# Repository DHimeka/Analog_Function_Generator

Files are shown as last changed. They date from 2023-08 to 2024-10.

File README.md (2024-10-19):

# 🎛️ Analog Function Generator
This project is a fully functional function generator designed during the third semester for the module EN2091 - Laboratory Practice and Projects. It incorporates essential features commonly found in laboratory-grade devices, combining versatility with performance.

  

## Usage/Examples

Usage examples will be included here, showcasing how to operate the function generator for various applications.

## Features

- Generation of sine, square, triangular, sawtooth, and PWM waveforms
- Frequency control from 20Hz to 20kHz
- Amplitude control from 0V to 20V with DC offset adjustment
- Compatibility with a 50 Ω load

## Introduction

This is the project done during the third semester for the module EN2091 - Laboratory Practice and Projects. During the course of this project, Our team had the privilege of designing and developing a fully functional function generator that seamlessly incorporates essential features commonly found in laboratory-grade devices. With a clear focus on versatility and performance, we harnessed the potential of basic electronic components, including opamps, transistors, resistors, capacitors, and potentiometers, to achieve waveform generation and control with optimum precision. Through an extensive research and a meticulous design, we successfully utilized analog electronic calculations to generate sine, square, triangular, sawtooth, and PWM waveforms. We ensured accurate frequency control across the impressive range of 20Hz to 20kHz, empowering users to tailor the function generator to their specific experimental requirements. A key aspect of the project was the robust control over amplitude and DC offset. Employing feedback mechanisms and precise opamp configurations, we allowed users to manipulate the output voltage from a 0V to 20V and introduce desired DC offsets for waveform customization. Throughout the endeavor, we encountered and various challenges, from refining the circuits iteratively to optimize performance, building up enclosures, making pcbs to presenting a marketable prooduct. Yet the outcome was worthful and impressive. The result is a fully functional and adaptable function generator, seamlessly blending the artistry of creative circuit design with the precision of engineering finesse.

## Electronic Design

### Design Guidelines
The project adhered to specific design requirements, including waveform generation, frequency, amplitude, PWM control, and 50 Ω load compatibility. These guidelines influenced the electronic design decisions.

### Waveform Generation
- **Square Wave and PWM Wave Generation:** A Schmitt trigger circuit generates square waves, which can be further modified to achieve PWM waves with adjustable duty cycles.
- **Triangular Wave and Sawtooth Generation:** Triangular and sawtooth waveforms are generated through a capacitor-based charging and discharging process, with frequency control.
- **Sine Wave Generation:** A Wien bridge oscillator generates sine waves, which can be adjusted for frequency.

### Output Circuit
The output circuit handles waveform selection, probe selection (1x and 10x), amplitude control, and push-pull amplification to drive a 50 Ω load.

### Calculations and Component Selection
Careful component selection and calculations were crucial for ensuring proper functionality. The NE5532n operational amplifier was chosen for its low noise and appropriate gain-bandwidth product. Transistors TIP31C and TIP32C were selected to handle the required power and current.

### Simulations
NI Multisim was used for circuit simulations to validate the design before proceeding to PCB fabrication. Simulations confirmed that the circuit met the desired specifications.

### Testing
After simulation, the circuit was implemented on a breadboard and tested. Issues related to waveform interference and instability were addressed through careful circuit adjustment and troubleshooting.

### PCB Designing and Soldering
The PCB was designed using Altium and printed through JLCPCB in a two-layer configuration. Soldering was done with locally sourced components to create a physical circuit.

## Results

The project successfully achieved the following results:
- Generation of square, triangular, sawtooth, and sine waves within the specified frequency and amplitude ranges.
- PWM wave generation with adjustable duty cycles.
- Compatibility with a 50 Ω load.

## Enclosure Design

The enclosure for the function generator was designed using Solidworks 2020, ensuring a suitable physical housing for the device.

## Discussions

The project team encountered challenges with waveform distortions at high frequencies. Strategies to mitigate these distortions, including the use of high-quality components and minimizing wire resistance, were discussed.

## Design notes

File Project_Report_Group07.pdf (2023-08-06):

## University of Moratuwa

## Faculty of Engineering

## Department of Electronic & Telecommunication Engineering

EN2091 - Laboratory Practice and Projects Group 07
Project Report - Analog Function Generator

Group Members

Index No. | Name
200051J 200222K 200396U 200564J | Arukgoda A.M.O Himeka S.H.D Miranda C.M.C.C Samaraweera D.T

Abstract

In this report there is a detailed description of how to build an analog function generator which can generate Sine, Saw-tooth, Square (with adjustable duty cycle) waves with adjustable amplitude, frequency and a DC shift. The amplitudes can be varied from 0 V to 10 V and frequencies can be varied from 20 Hz to 20 kHz. This project was done by mainly using op-amps, resistors and capacitors.

## Contents

1 Introduction | 1
2 Electronic Design | 1
3 Calculations and Component Selection | 4
4 Simulations | 5
5 Testing | 6
6 PCB Designing and Soldering | 6
7 Results | 7
8 Enclosure Design | 8
9 Discussions | 8
10 Acknowledgement | 9
11 Bibliography | 9
12 Appendices | 10

## 1 Introduction

For this project, we were asked to make a fully functional function generator which includes all the key functionalities of a laboratory function generator.Generation of sine, square, triangular, sawtooth and PWM wave forms are the main functionalities of the function generator.Other than that, this function generator is capable of changing the frequency of the wave forms from 20Hz to 20kHz and the amplitude from 0 to 20V. Adding a DC offset to the wave forms and add a changing the duty cycle of square wave are the other functionalities of the function generator.In the past, these functionalities were produced b7y some popular Integrated Circuits(ICs).Now these old analog ICs are replaced with new Direct Digital Synthesis chips.In this project, only opamps, transistors, resistors capacitors and potentiometers were used to generate all the wave forms.In this report, the different techniques which were used to generate wave forms and change the characteristics of the wave forms will be described.

## 2 Electronic Design

### 2.1 Design Guidelines

For the analog function generator project we were given the following specifications to be fulfilled.

1. The function generator should be able to generate sine, triangular, saw-tooth, square and pulse width modulation (PWM) waves.
2. The frequencies of the waves should be able to vary from 20 Hz to 20 kHz.
3. The amplitudes of the waves should be able to vary up to 20 V peak-topeak.
4. In PWM wave, the pulse width should be able to vary from 1% up to 99%.
5. The function generator should be able to supply the waves to a 50 Ω load.

### 2.2 Waveform Generation

As the given specifications, the function generator should be able to generate five functions namely, sine wave, square wave, triangular wave and PWM wave. We used separate methods to generate these wave forms to reduce the effect of one waveform on other wave forms.

### 2.2.1 Square Wave and PWM wave

Generation

Both the square wave and PWM wave forms can be generated using the same circuit because the square wave is the PWM wave with a duty cycle of 50%.
To generate the square wave, we used a schmitt trigger circuit.Schmitt trigger circuit produces a square wave when producing clock or timing signals which swaps between high and low.The frequency of the square wave depends on the value of Resistance and the capacitance.

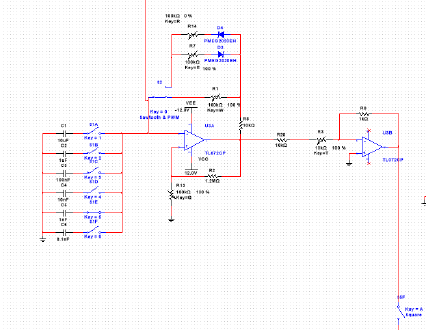
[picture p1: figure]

Figure 1: Square wave generator circuit.

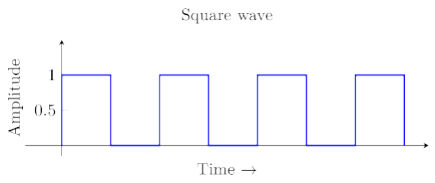
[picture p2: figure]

Figure 2: Square wave

The square wave generated from Schmitt trigger circuit will be headed to a Inverting attenuator in order reduce the output voltage to a more useful voltage.It is because the the highest output voltage from the relaxation oscillator will be not useful at this point of the circuit.
The duty cycle of the square wave generated by the Schmitt trigger circuit can be controlled by the Schottky Diodes circuit.

Figure 3: Square wave attenuator circuit.

By adjusting the potentiometers we can control the duty cycle percentage. The frequency of the square wave depends on the value of Resistance and the capacitance.

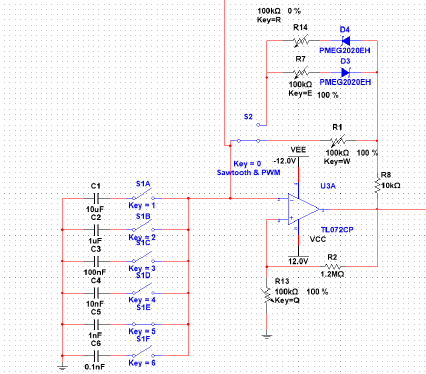
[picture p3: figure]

Figure 4: PWM circuit.

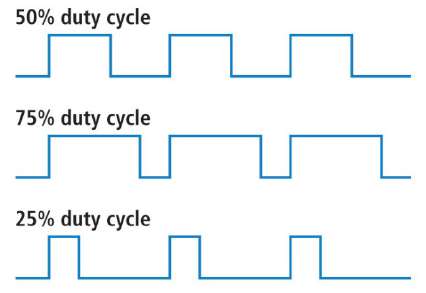
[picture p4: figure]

Figure 5: PWM Wave

### 2.2.2 Triangular Wave and Saw tooth

Generation

The triangular waveform is generated using the simple charging and discharging property of a capacitor.The frequency can be varied by changing the value of the capacitor and the variable resistors of the Schmitt

Trigger circuit.This is the same that was used to generate square wave. The out from

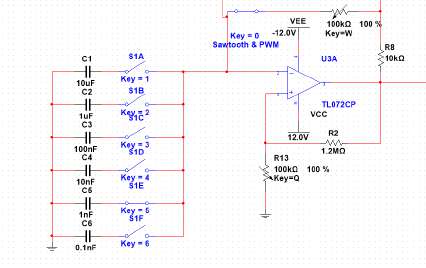
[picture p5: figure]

Figure 6: Schmitt trigger circuit of triangular wave generator

the capacitor panel will then be connected to a non-inverting amplifier that ”picks off” the triangle wave from the capacitor.Non-inverting amplifier configurations are useful because they have extremely high input impedance. The actual charge on the capacitor is very small, and any significant current draw from that point can ruin the operation of the relaxation oscillator. The

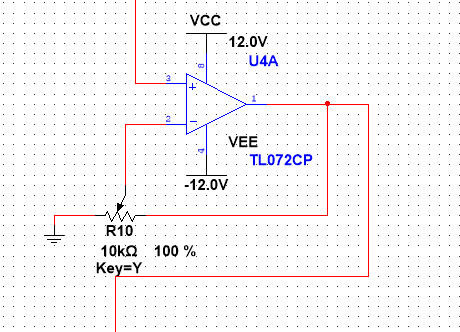
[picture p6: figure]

Figure 7: Non-inverting amplifier of triangular wave generating circuit

Figure 8: Triangular wave

saw-tooth waveform is generated using the simple charging and discharging property of a capacitor and the Schottky diodes circuit along with the Schmitt Trigger circuit .The ramp of the saw-tooth can be controlled by potentiometers.Frequency control is same as the triangular waveform.

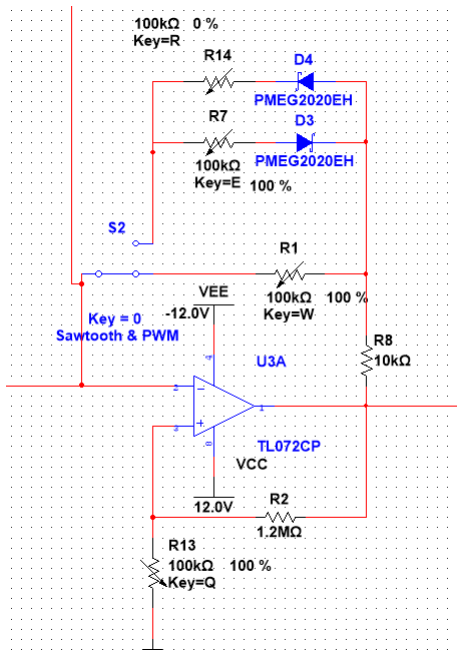
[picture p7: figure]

Figure 9: Saw tooth waveform generating circuit

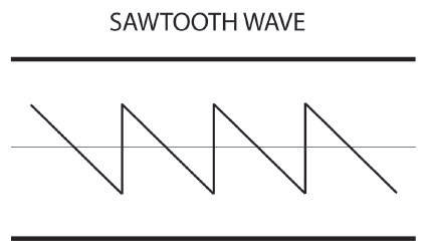
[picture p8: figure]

Figure 10: Sawtooth wave

### 2.2.3 Sine Wave Generation

To generate the sine wave, in our project, wien bridge oscillator is used.This generates a sine wave at the resonance frequency (fr), given by the equation,

F =

1
2πrc
The frequency of the sine wave can be changed by varying the values of the two resistors or

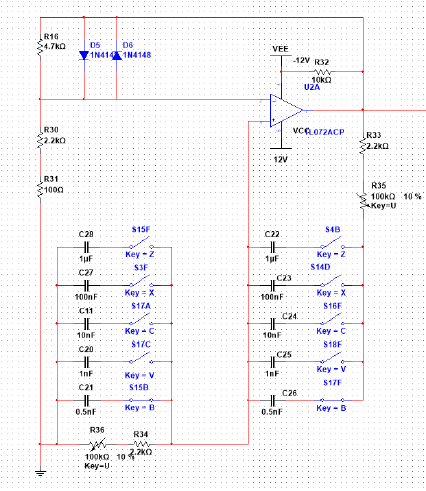
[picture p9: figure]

Figure 11: Wien bridge oscillator for sine wave generation

Figure 12: Sine wave.

the two capacitors simultaneously. An Inverting Amplifier that is used to calibrate the sine wave.A low-pass filter before will be useful to eliminate some of the overtones and make a prettier sine wave.A high pass filter after the amplifier will eliminate any offset remaining after the drift correction.

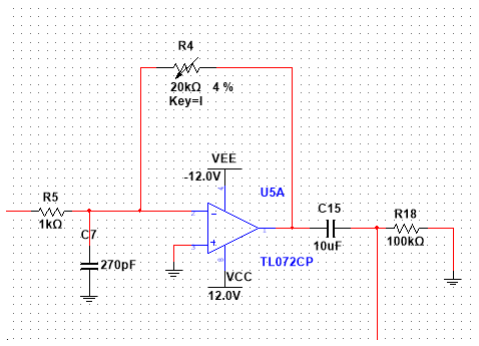
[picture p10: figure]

Figure 13: Inverting amplifier of sine wave generating circuit

### 2.3 Output Circuit

The output circuit of the function generator gives the ability to change the amplitudes, give dc shifts and to provide the output through a small load.The amplitude variation is done using an inverting amplifier. A push-pull amplifier is used to drive the load.

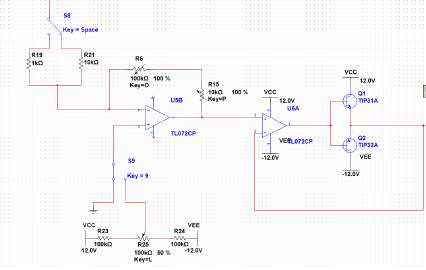
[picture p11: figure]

Figure 14: Output circuit

### 2.3.1 Waveform selection

Between the sine,square,triangular circuits and the output circuit, a switch is used to select which waveform generating circuit should be connected to the output circuit.

Figure 15: Waveform selection

### 2.3.2 Probe selection

This switch is used to change the probe between 1x and 10x. It can be used to change the amplitude range.

### 2.3.3 Amplitude control

An inverting amplifier is being used to vary the amplitude of he waveform.The main amplitude change of the wave forms is done using this amplifier.

### 2.3.4 Push pull amplifier

At the output stage of the function generator a push-pull amplifier is used to am-

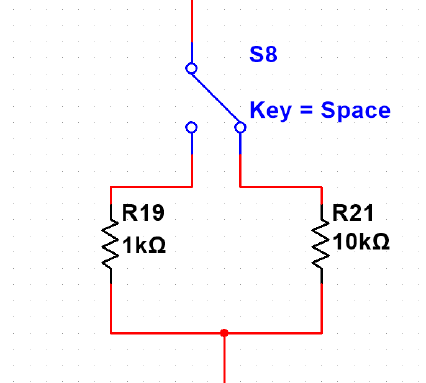
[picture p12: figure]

Figure 16: Probe selection

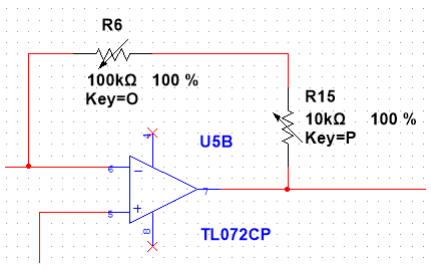
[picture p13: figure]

Figure 17: Amplitude Control

plify the current. This helps it to drive a small load without any distortion in the wave. In the design a class-AB push-pull amplifier is used.The two pnp and npn transistors are complementary to each other. The npn transistor drives the output during the positive half cycle of the input while the pnp transistor drives the output during the negative half cycle. These transistors should also be capable of handling the desired amount of power and current. The two diodes keep both the transistors biased thus eliminating the crossover distortion.

## 3 Calculations and Component Selection

For the correct functionality of the function generator, selecting components is very important. We have done this using necessary calculations and by referring to the data sheets of the components.

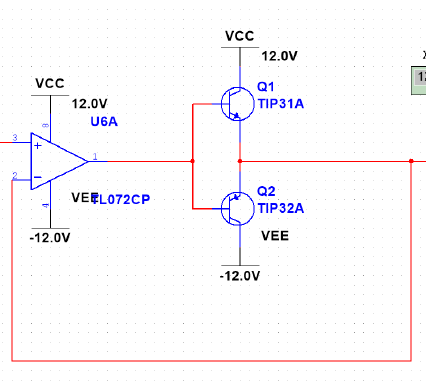
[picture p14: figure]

Figure 18: Push pull amplifier

### 3.1 Opamp selection

In this circuit, all the waveform generations and amplifications are done using opamps.We have selected NE5532n opamp to meet the given specifications. This low noise op-amp

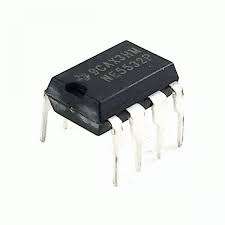
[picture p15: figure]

Figure 19: NE5532 Opamp

has a high slew rate of 9 V/µs. This is an important factor specially in square wave generation. This op-amp also has a gainbandwidth product(GBP) of 10 MHz. The required bandwidth for the function generator is 20 kHz. Therefore the maximum gain that can be achieved without any distortion can be calculated as below.

M aximumGain =

10x10⁶
2x10³ = 500

This is more than sufficient to generate the 20V peak to peak output waveforms.

### 3.2 Transistor selection

To drive a small current through the function generator, push pull amplifier is used. Maximum power calculations of 50Ω load is given below.

M aximumP ower =

10²
50 = 2W

M aximumGain =

10
50 = 200mA

The transistors we used are TIP31C and TIP32C and these transistors are capable of providing 40W power and a maximum collector current of 3A and these can handle required power and current easily.

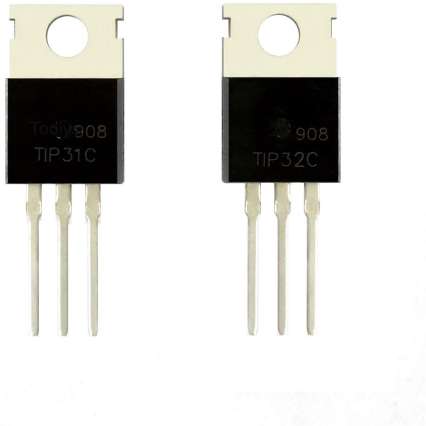
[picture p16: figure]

Figure 20: TIP31C AND TIP32C Transistors

## 4 Simulations

We used NI Multisim to simulate the circuit before designing the PCB.All the required waveforms were generated and their characteristics could be changed correctly using the simulation.NI Multisim simulation is shown below.

Figure 21: NI Multisim simulation circuit

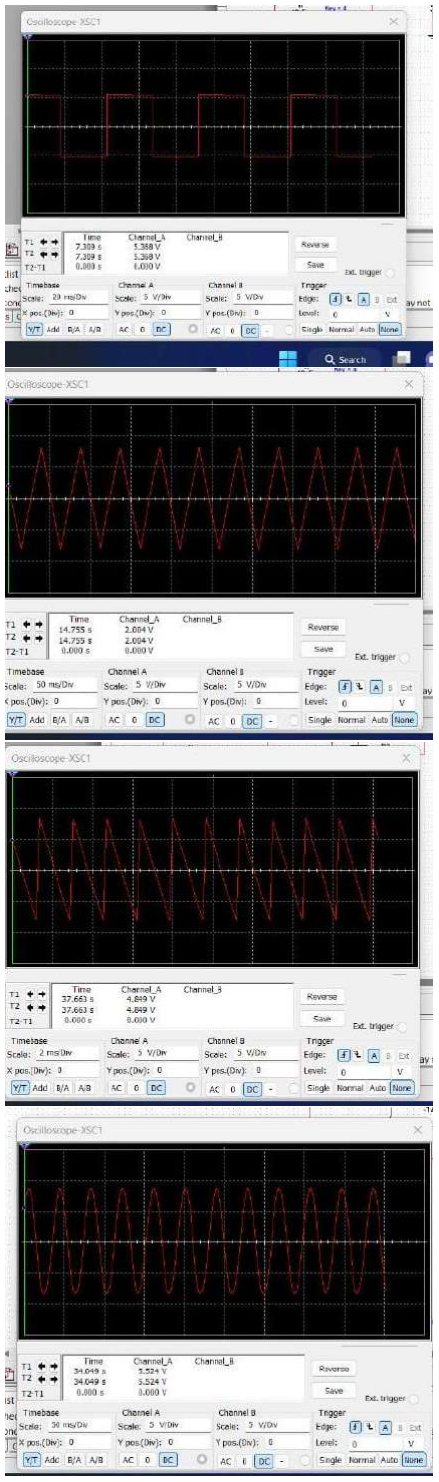
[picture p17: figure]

Figure 22: NI Multisim simulation waveforms

## 5 Testing

After the circuit simulations, we implemented the circuit in the breadboard and tested it. We encountered some issues but after a few attempts, we could get clear waveforms with adjustable frequencies and amplitudes in the advised range. The Wien bridge oscillator generated sin wave was affecting the other square and triangular wave forms. We could minimize this issue up to a certain level using decoupling capacitors for each IC.We concluded that the major instabilities of the wave forms were due to loose connections and a breadboard and wire resistance.

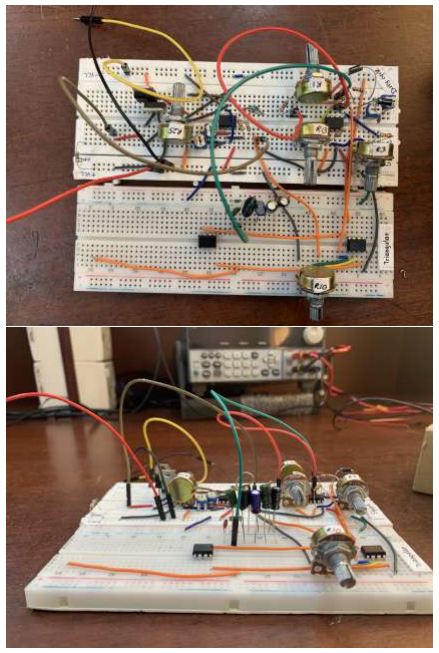
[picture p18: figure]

Figure 23: Breadboard Testing.

## 6 PCB Designing and Soldering

Next, we proceeded with the PCB design. We designed a two-layer PCB using Altium designing 22.4.1. The two planes were connected to the ground. We added a separate copper pour for the copper plane for better signal quality. Since our circuit does draw a current of more than A, we set our trace normal line trace width to 0.2mm while the power line width was kept at 3mm. We

## 7 Results

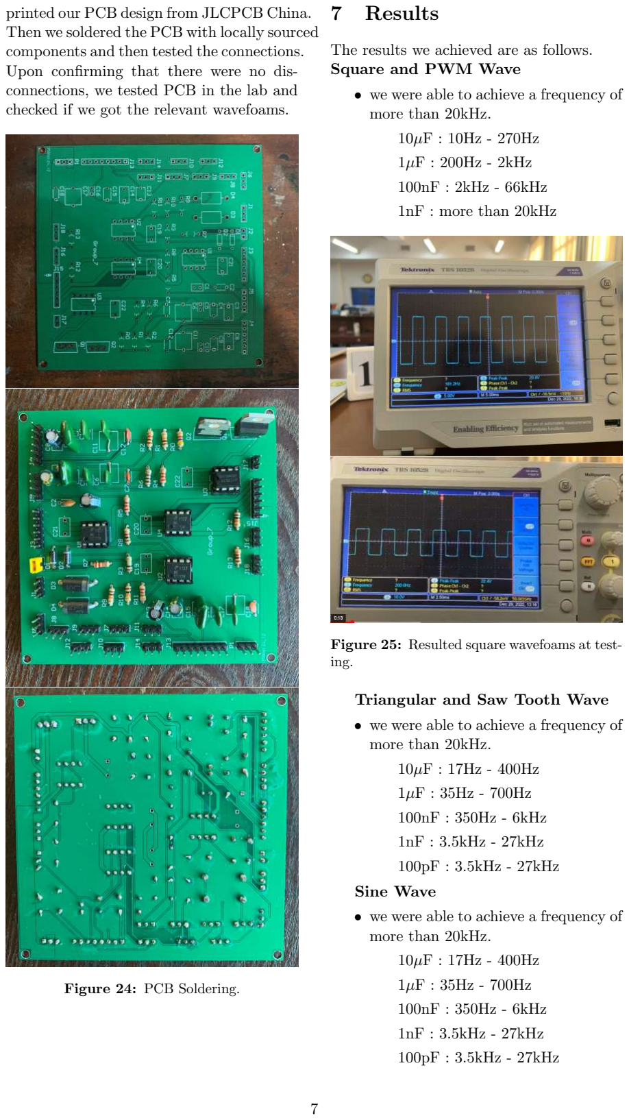
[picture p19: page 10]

printed our PCB design from JLCPCB China. Then we soldered the PCB with locally sourced components and then tested the connections. Upon confirming that there were no disconnections, we tested PCB in the lab and checked if we got the relevant wavefoams.

Figure 24: PCB Soldering.

The results we achieved are as follows. Square and PWM Wave
- we were able to achieve a frequency of more than 20kHz.

10µF : 10Hz - 270Hz

1µF : 200Hz - 2kHz

100nF : 2kHz - 66kHz

1nF : more than 20kHz

Figure 25: Resulted square wavefoams at testing.

Triangular and Saw Tooth Wave
- we were able to achieve a frequency of more than 20kHz.

10µF : 17Hz - 400Hz

1µF : 35Hz - 700Hz

100nF : 350Hz - 6kHz

1nF : 3.5kHz - 27kHz

100pF : 3.5kHz - 27kHz

Sine Wave
- we were able to achieve a frequency of more than 20kHz.

10µF : 17Hz - 400Hz

1µF : 35Hz - 700Hz

100nF : 350Hz - 6kHz

1nF : 3.5kHz - 27kHz

100pF : 3.5kHz - 27kHz

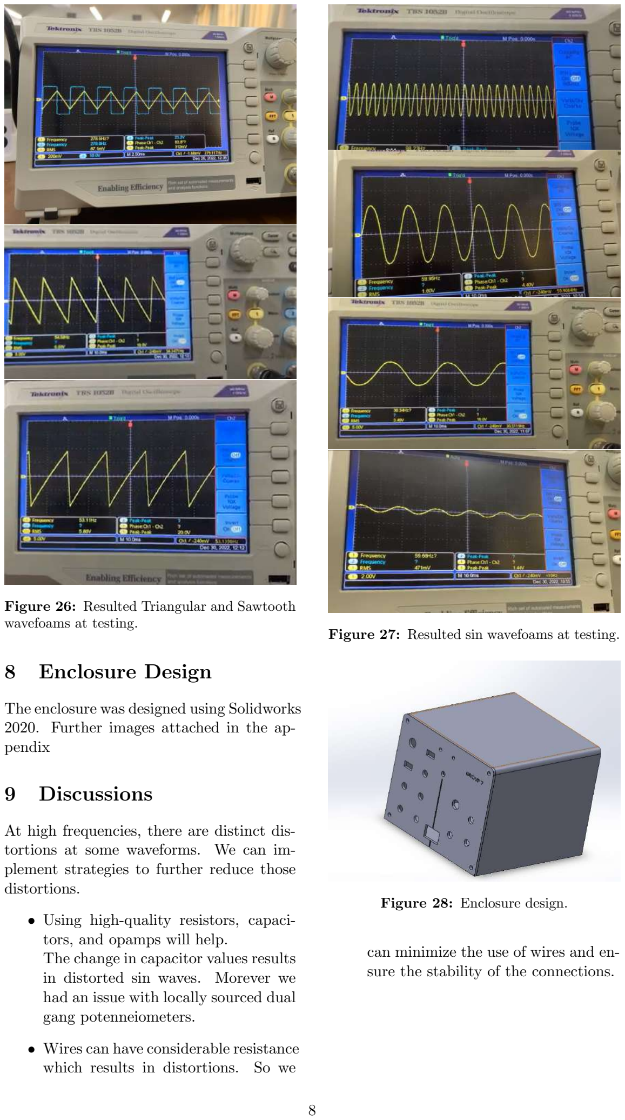
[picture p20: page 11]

Figure 26: Resulted Triangular and Sawtooth wavefoams at testing.

## 8 Enclosure Design

The enclosure was designed using Solidworks 2020. Further images attached in the appendix

## 9 Discussions

At high frequencies, there are distinct distortions at some waveforms. We can implement strategies to further reduce those distortions.

- Using high-quality resistors, capacitors, and opamps will help.
The change in capacitor values results in distorted sin waves. Morever we had an issue with locally sourced dual gang potenneiometers.
- Wires can have considerable resistance which results in distortions. So we

Figure 27: Resulted sin wavefoams at testing.

Figure 28: Enclosure design.

can minimize the use of wires and ensure the stability of the connections.

## 10 Acknowledgement

Throughout this project, we were guided and aided by so many personalities. We would like to extend our sincere gratitude to our project mentors, Mr.Pahan, Mr.Chamath and Ms. Sandani, whose unwavering commitment and keen enthusiasm in our undertaking contributed to the success of our project. Additionally, we would like to thank all those who contributed in even the slightest way for us to achieve this goal.

## 11 Bibliography

1. Generating Sine Waves from Triangle Waves (https://www.analog.com/en/analog-dialogue/studentzone/studentzone-september-2021.html)
2. Sine Wave Generator using IC 741 OP AMP Operational Amplifier (https://www.electroniclinic.com/sine-wave-generator-using-ic-741-op-amp-operational-amplifier/)
3. Wien Bridge Sine Wave Oscillator / Generator (https://www.electronics-notes.com/articles/analogue_circuits/operational-amplifier-op-amp/wien-bridge-sine-wave-oscillator-generator.php)
4. Philip Karantzalis, Aaron Schultz, and Catherine Chang,Lower Power Op Amp: Utility Sine Wave (https://www.analog.com/en/technical-articles/lower-power-op-amp-utility-sine-wave.html)
5. Waveform Generator using Op Amp 741 (https://vikramlearning.com/jntuh/notes/ic-applications-and-hdl-simulation-lab/waveform-generator-using-op-amp-741/298)
6. Wien Bridge Oscillators (https://learnabout-electronics.org/Oscillators/osc34.php)
7. Limited Wien-Bridge Oscillator Amplitude (https://electronics.stackexchange.com/questions/167196/limited-wien-bridge-oscillator-amplitude)
8. Analog Function Generator (https://www.instructables.com/Function-Generator/)
9. Increase Amplifier Output Drive Using a Push-Pull Amplifier Stage (https://www.analog.com/en/technical-articles/increase-amplifier-output-drive-using-a-push-pull-amplifier-stage.html)

## 12 Appendices

### 12.1 Schematic Design

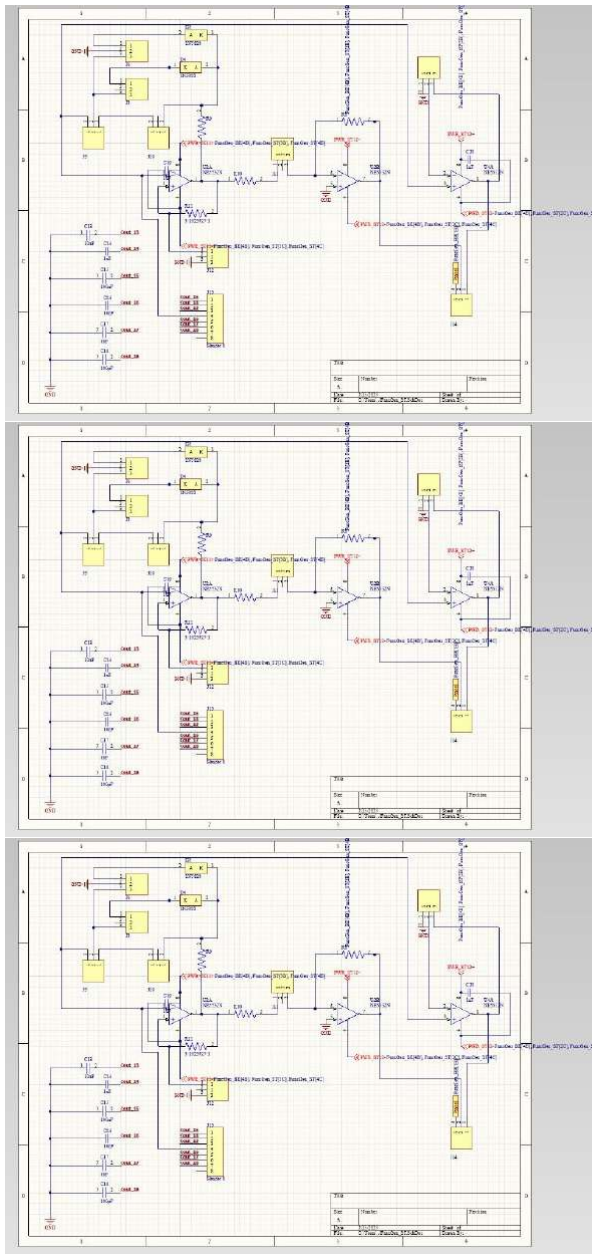
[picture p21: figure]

Figure 29: Schematic

### 12.2 PCB Design

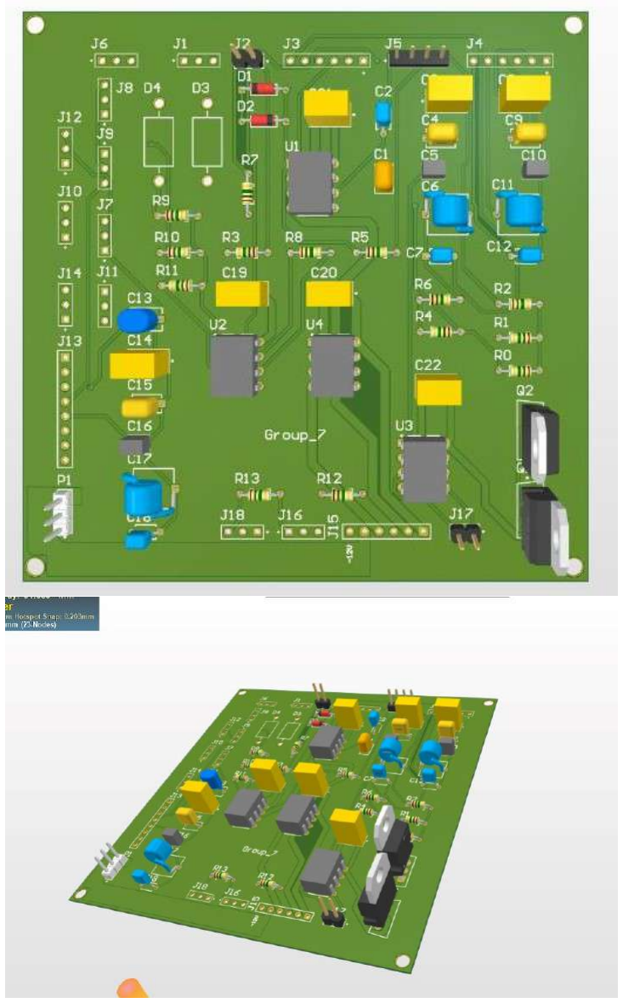
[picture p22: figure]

Figure 30: PCB

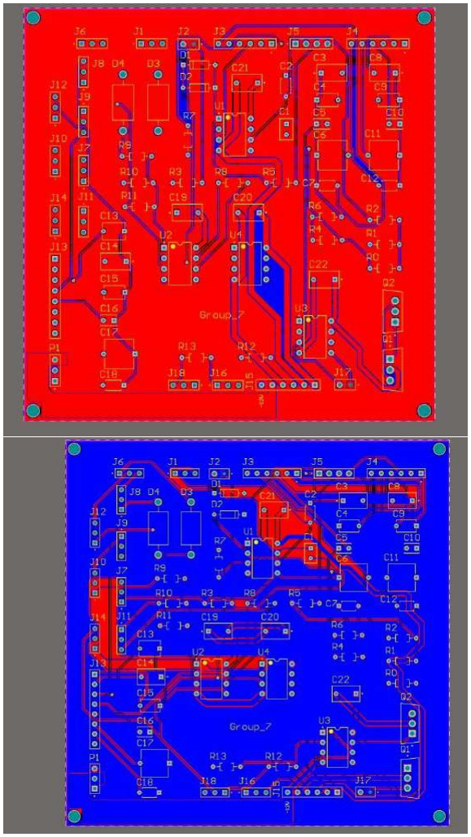
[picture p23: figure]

Figure 31: PCB

### 12.3 Enclosure Design

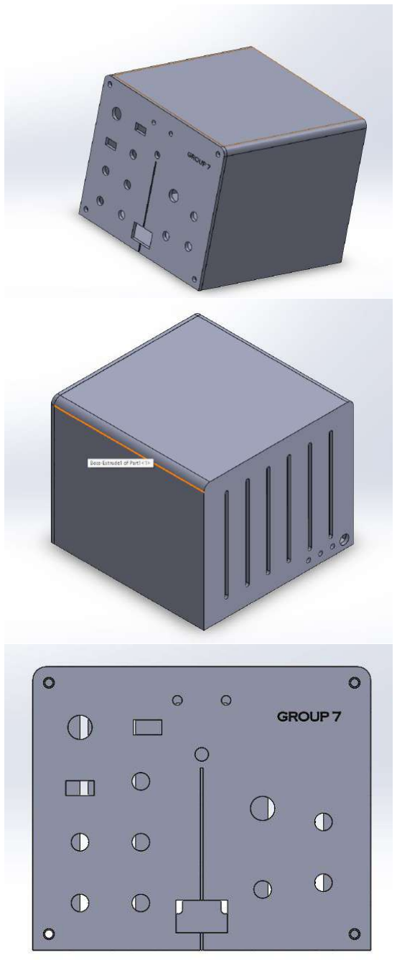
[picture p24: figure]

Figure 32: Enclosure

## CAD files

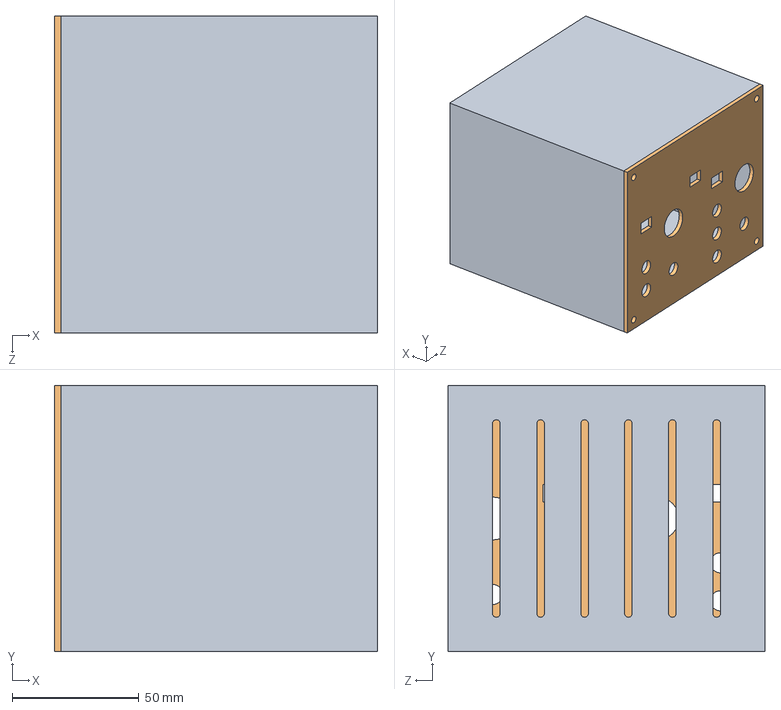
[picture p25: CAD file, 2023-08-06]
Enclosure/Assem1.SLDASM
127.5 x 105.0 x 125.0 mm

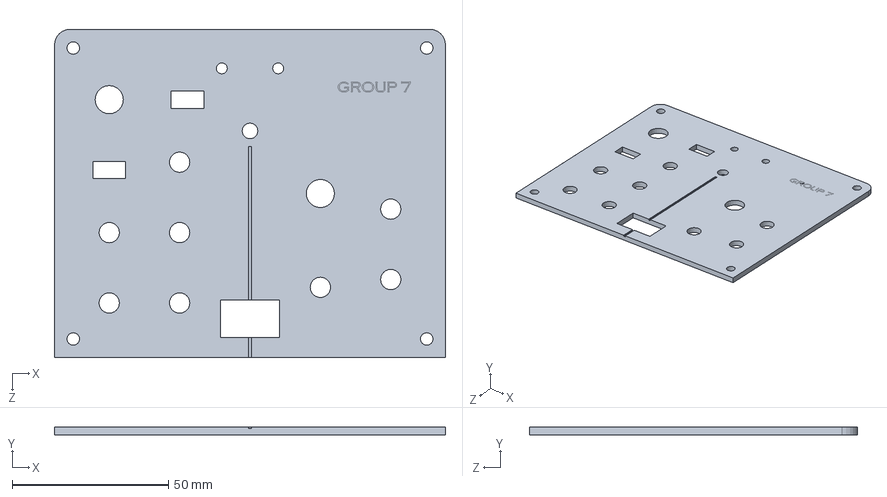
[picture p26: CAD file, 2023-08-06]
Enclosure/Part2.SLDPRT
125.0 x 2.50 x 105.0 mm

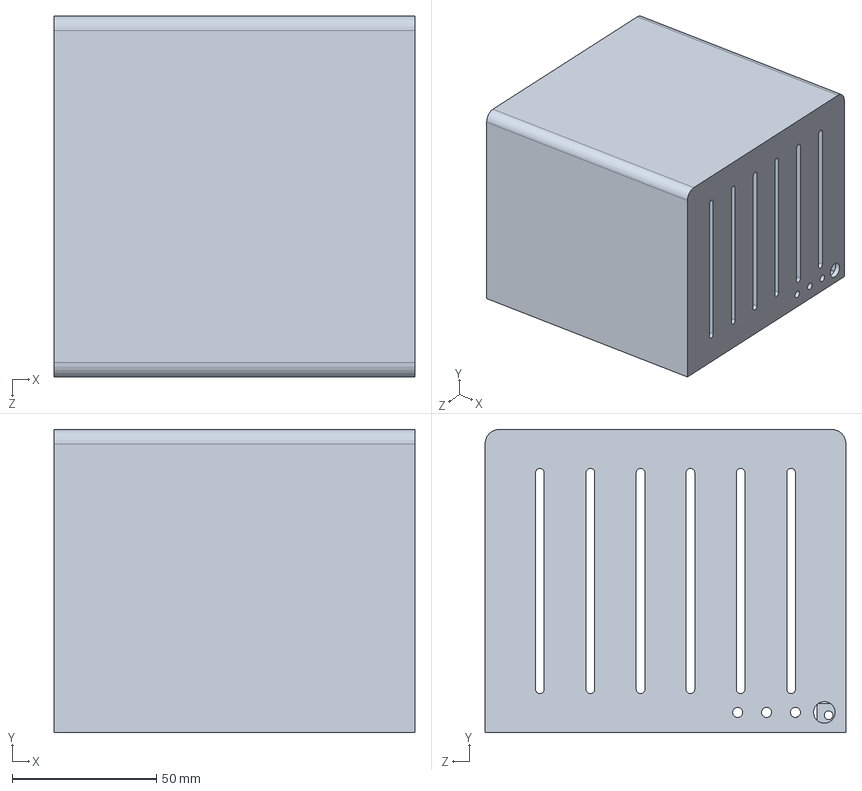
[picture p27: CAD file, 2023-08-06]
Enclosure/Part1.SLDPRT
125.0 x 105.0 x 125.0 mm

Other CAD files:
Enclosure/Part1.STL
Enclosure/Part2.STL

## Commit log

2023-08-06 Solidwork Files
    [Assem1.SLDASM, Part1.SLDPRT, Part1.STL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]
2023-08-06 PCB Files
    [FuncGen_BE.SchDoc, FuncGen_ST.SchDoc, Function_gen_schem.SchDoc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]
